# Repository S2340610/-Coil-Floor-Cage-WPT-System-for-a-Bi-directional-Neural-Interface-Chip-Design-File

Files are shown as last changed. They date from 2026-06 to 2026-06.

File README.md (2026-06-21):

# Coil-Floor Wireless Power Transfer System for a Bi-directional Neural Interface Chip

Open-hardware design files for the 156 kHz inductive WPT system described in:

> X. Liu and S. Wang, "Development and Evaluation of a Coil-Floor Cage Wireless Power Transfer System for a Bi-directional Neural Interface Chip," \*IEEE Journal of Solid-State Circuits\*, 2025.

The system supplements the battery of a 32-channel bi-directional ECoG headstage during freely moving murine electrophysiology, covering a 63 × 63 cm² open-field arena with a 3 × 3 modular coil-tile floor. All design files are released to allow replication outside specialist fabrication facilities.

\---

## Repository Structure

```
.
├── Coil\_housing\_model/       # OpenSCAD parametric former for the primary coil tiles
├── Receiver\_1N5819/          # Altium PCB project — receiver pipeline
│   ├── Receiver\_1n5819.PcbDoc
│   ├── Sheet2.SchDoc
│   └── Wireless\_RX\_Li-charger.PrjPcb
└── Transmitter\_H/            # Altium PCB project — H-bridge transmitter
    ├── Transmitter\_Hbridge.PcbDoc
    ├── Sheet2.SchDoc
    └── Transmitter\_H.PrjPcb
```

\---

## System Overview

|Parameter|Value|
|-|-|
|Carrier frequency|156 kHz|
|Arena coverage|63 × 63 cm² (3 × 3 tile array)|
|Tile size|21 × 21 cm²|
|Peak power transfer efficiency|60.1% at 6 cm vertical separation|
|Tilt retention at 45°|74.2% of peak PTE|
|Operational volume|56.6% of per-tile volume above coil floor|
|Headstage power budget|5 mW|
|Total system cost|≈ £90 (commodity parts)|

\---

## Hardware

### Transmitter

* **Oscillator:** TLC555 astable multivibrator, 50% duty cycle, tunable 29.8–328 kHz
* **Inverter:** CD74HC4049E hex inverter generating complementary drive signals
* **Gate drivers:** IRS2113 × 2 half-bridge drivers with bootstrap supply
* **H-bridge:** IRFZ44N × 4 N-channel MOSFETs, V\_pp = 38 V across primary tank
* **Primary tank:** Hand-wound 0.8 mm enamelled copper wire on 3D-printed PLA former, L₁ = 85.5 µH, C₀ = 12.2 nF
* **Supply:** 19 V DC adapter; on-board LM7812 (12 V gate rail) and L7805 (5 V logic rail)

### Receiver (Headstage)

* **Secondary tank:** Würth WE-WPCC 760308101303 litz-wound coil, L₂ = 47 µH, C₂ = 22.2 nF
* **Rectifier:** 1N5819 Schottky full-bridge, 2V\_f ≈ 0.68 V drop
* **LDO:** LDL1117S50R, V\_out = 5.0 V (requires V\_in ≥ 6.2 V)
* **Charger:** MCP73831T-4ADI/OT, 1 mA CC/CV profile (R\_prog = 1 MΩ)
* **Battery:** LIR1220 lithium-polymer coin cell

\---

## Replication Notes

**Coil winding:** All tiles must be wound in the same direction. Shared-edge currents then flow in opposition, so tile fields add constructively at every inter-tile boundary. A checkerboard winding creates flux nulls between tiles and degrades the operational envelope.

**Resonance tuning:** The tank capacitance follows the Thomson relation C = 1/(4π²f²L). Re-tune C₀ if the measured inductance of your hand-wound coil deviates from 85.5 µH. A single capacitor value applies to all tiles in an array of any size.

**Scaling:** Adding tiles requires only printing additional PLA formers, winding extra coils, and adjusting C₀. Drive electronics, supply voltage, and operating frequency are unchanged. The 56.6% operational volume ratio is preserved for any array size under uniform winding.

**Ferrite backing:** Self-adhesive ferrite sheet bonded to the underside of each tile raises bare-coil inductance from 76 µH to 85.5 µH (+12%) without altering the winding geometry.

\---

## Software / Tools Required

* [Altium Designer](https://www.altium.com/) — for PCB and schematic files (`.PcbDoc`, `.SchDoc`, `.PrjPcb`)
* [OpenSCAD](https://openscad.org/) — for the parametric coil former (`.scad`)

Gerber outputs and BOM are available under `Receiver\_1N5819/Project Outputs for Wireless\_RX\_Li-charger/` and `Transmitter\_H/Project Outputs for Transmitter\_H/`.

\---

## Citation

If you use these design files in your work, please cite:

```bibtex
@article{liu2025wpt,
  author  = {Liu, Xiankang and Wang, Shiwei},
  title   = {Development and Evaluation of a Coil-Floor Cage Wireless Power Transfer System for a Bi-directional Neural Interface Chip},
  note   = {Manuscript submitted for publication},

&#x20; year    = {2025}
}
```

\---

## Acknowledgement

The authors thank the Edinburgh Microelectronics group for access to bench equipment and the headstage chip used for sizing the link budget.

\---

## Licence

Hardware design files are released under [CERN Open Hardware Licence v2 – Permissive (CERN-OHL-P)](https://ohwr.org/cern_ohl_p_v2.txt).

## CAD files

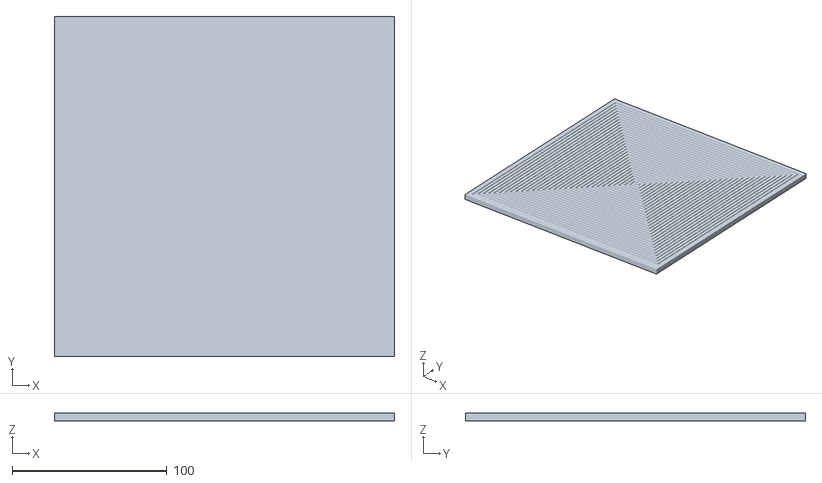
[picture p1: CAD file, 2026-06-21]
Coil_housing_model/base.stl
220.0 x 220.0 x 5.00
